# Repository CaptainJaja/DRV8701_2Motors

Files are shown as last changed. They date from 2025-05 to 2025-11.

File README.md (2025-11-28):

# Driver DRV8701 – Dual H-Bridge 40 V / 10 A (15 A peak)

> PCB designed with **KiCad** for driving **two brushed DC motors** up to 40 V / 10 A.
> Each channel uses a TI **DRV8701** driver paired with four **TPH1R403NL** power MOSFETs.
> The board integrates **encoder feedback** for PID control, as well as **current regulation** handled directly by the DRV8701.
> The current limit is set to **3 A**: above this value, the driver applies **PWM current chopping** to maintain the current below the set point.

---

## ⭐ Sponsor: PCBWay

This project was **sponsored by PCBWay**, who kindly provided the PCBs for prototyping.
The PCB quality is excellent and the support very responsive.

👉 **PCBWay Link:**


Thanks again to Liam and the PCBWay team for their support!

---

## Main Specifications

| Parameter | Value |
| --- | --- |
| Supply voltage VM | 7 – 40 V |
| Continuous current/motor | 10 A (4-layer PCB, 1 oz copper) |
| Peak current | 15 A (≤ 100 ms) |
| Chopped current limit | 3 A (via DRV8701) |
| Topology | 2 × full H-bridge (DRV8701 + 4 MOSFETs each) |
| Control signals | PH / EN / nSLEEP (TTL 3.3 V / 5 V) |
| LED indication | **EN** (active when nSLEEP = HIGH) |
| NeoPixel indication | Battery status (>25 V / 23–25 V / <23 V) |
| PCB dimensions | 100 mm × 40 mm |

---

## Thermal Management

* DRV8701 **exposed pad** connected to the GND plane through thermal vias.
* **TPH1R403NL (SOP-Advance)** MOSFETs soldered onto a large copper area + internal plane for heat spreading.
* Bulk decoupling capacitors: **470 µF / 50 V**, low ESR.

---

## PCB Views

### Component side

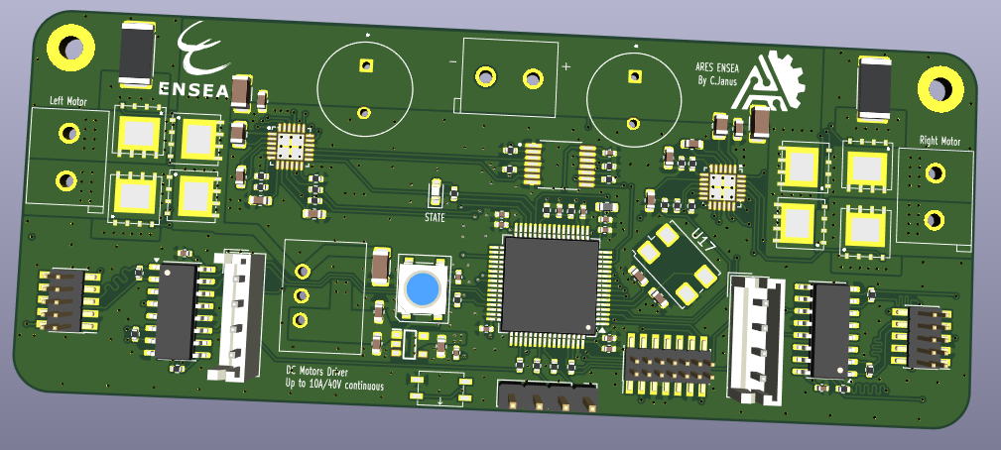
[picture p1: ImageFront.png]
PCB Front


### Bottom copper side

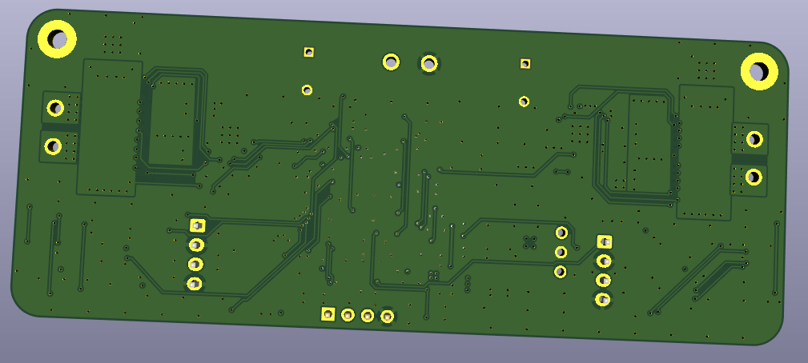
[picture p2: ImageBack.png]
PCB Back


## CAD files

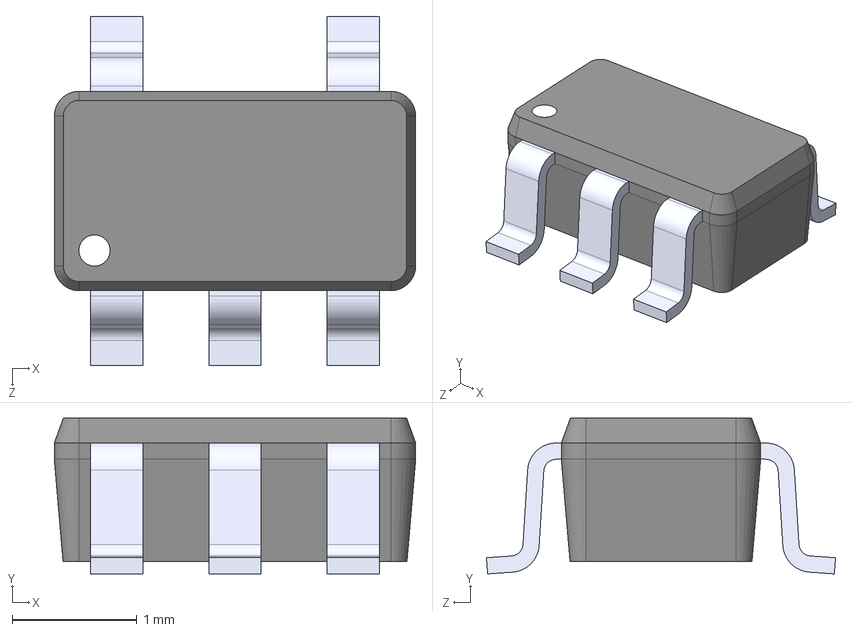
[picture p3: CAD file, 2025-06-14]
BU33SD5WG-TR/BU33SD5WG-TR.step
2.90 x 1.25 x 2.80 mm

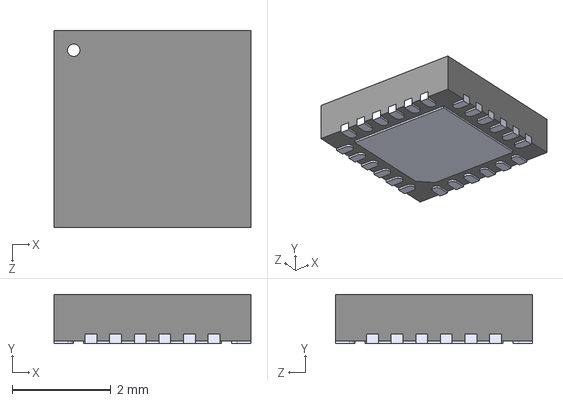
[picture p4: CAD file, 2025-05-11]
DRV8701ERGER/DRV8701ERGER.step
4.00 x 1.00 x 4.00 mm

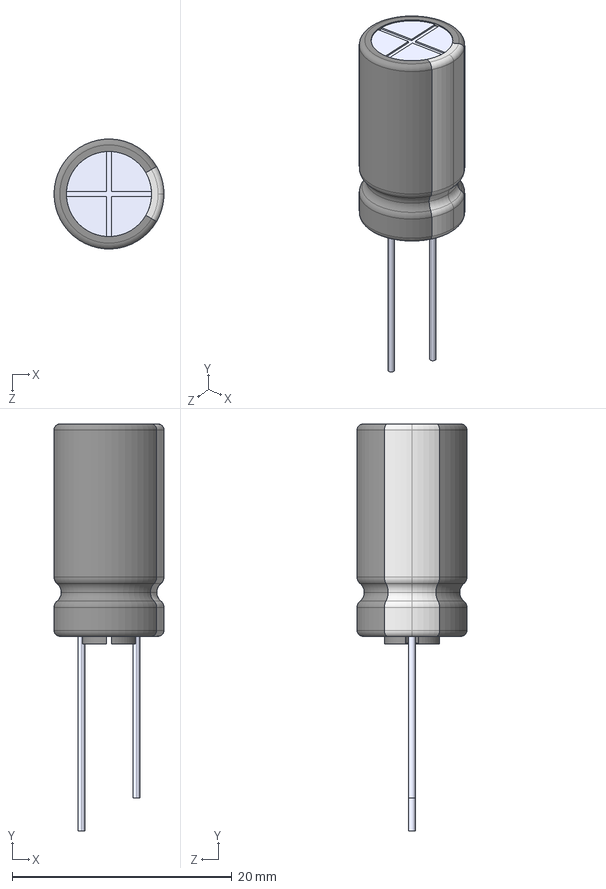
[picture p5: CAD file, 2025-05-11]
ECA1HHG471/ECA1HHG471.step
10.0 x 37.0 x 9.99 mm

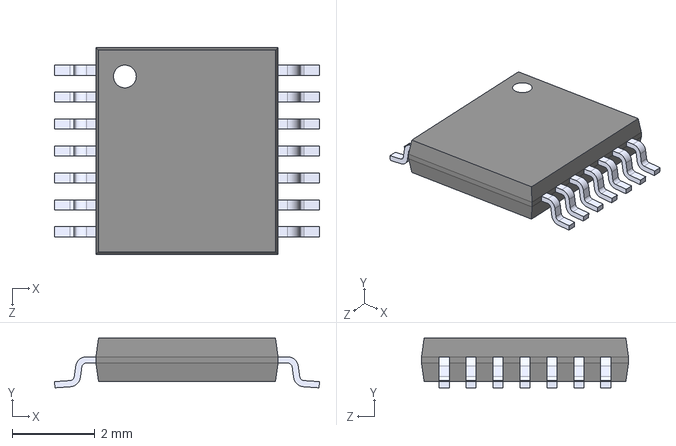
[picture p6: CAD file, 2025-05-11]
SN74HC125PWR/SN74HC125PWR.step
6.40 x 1.20 x 5.00 mm

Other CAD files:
switch_472121010111/472121010111.step

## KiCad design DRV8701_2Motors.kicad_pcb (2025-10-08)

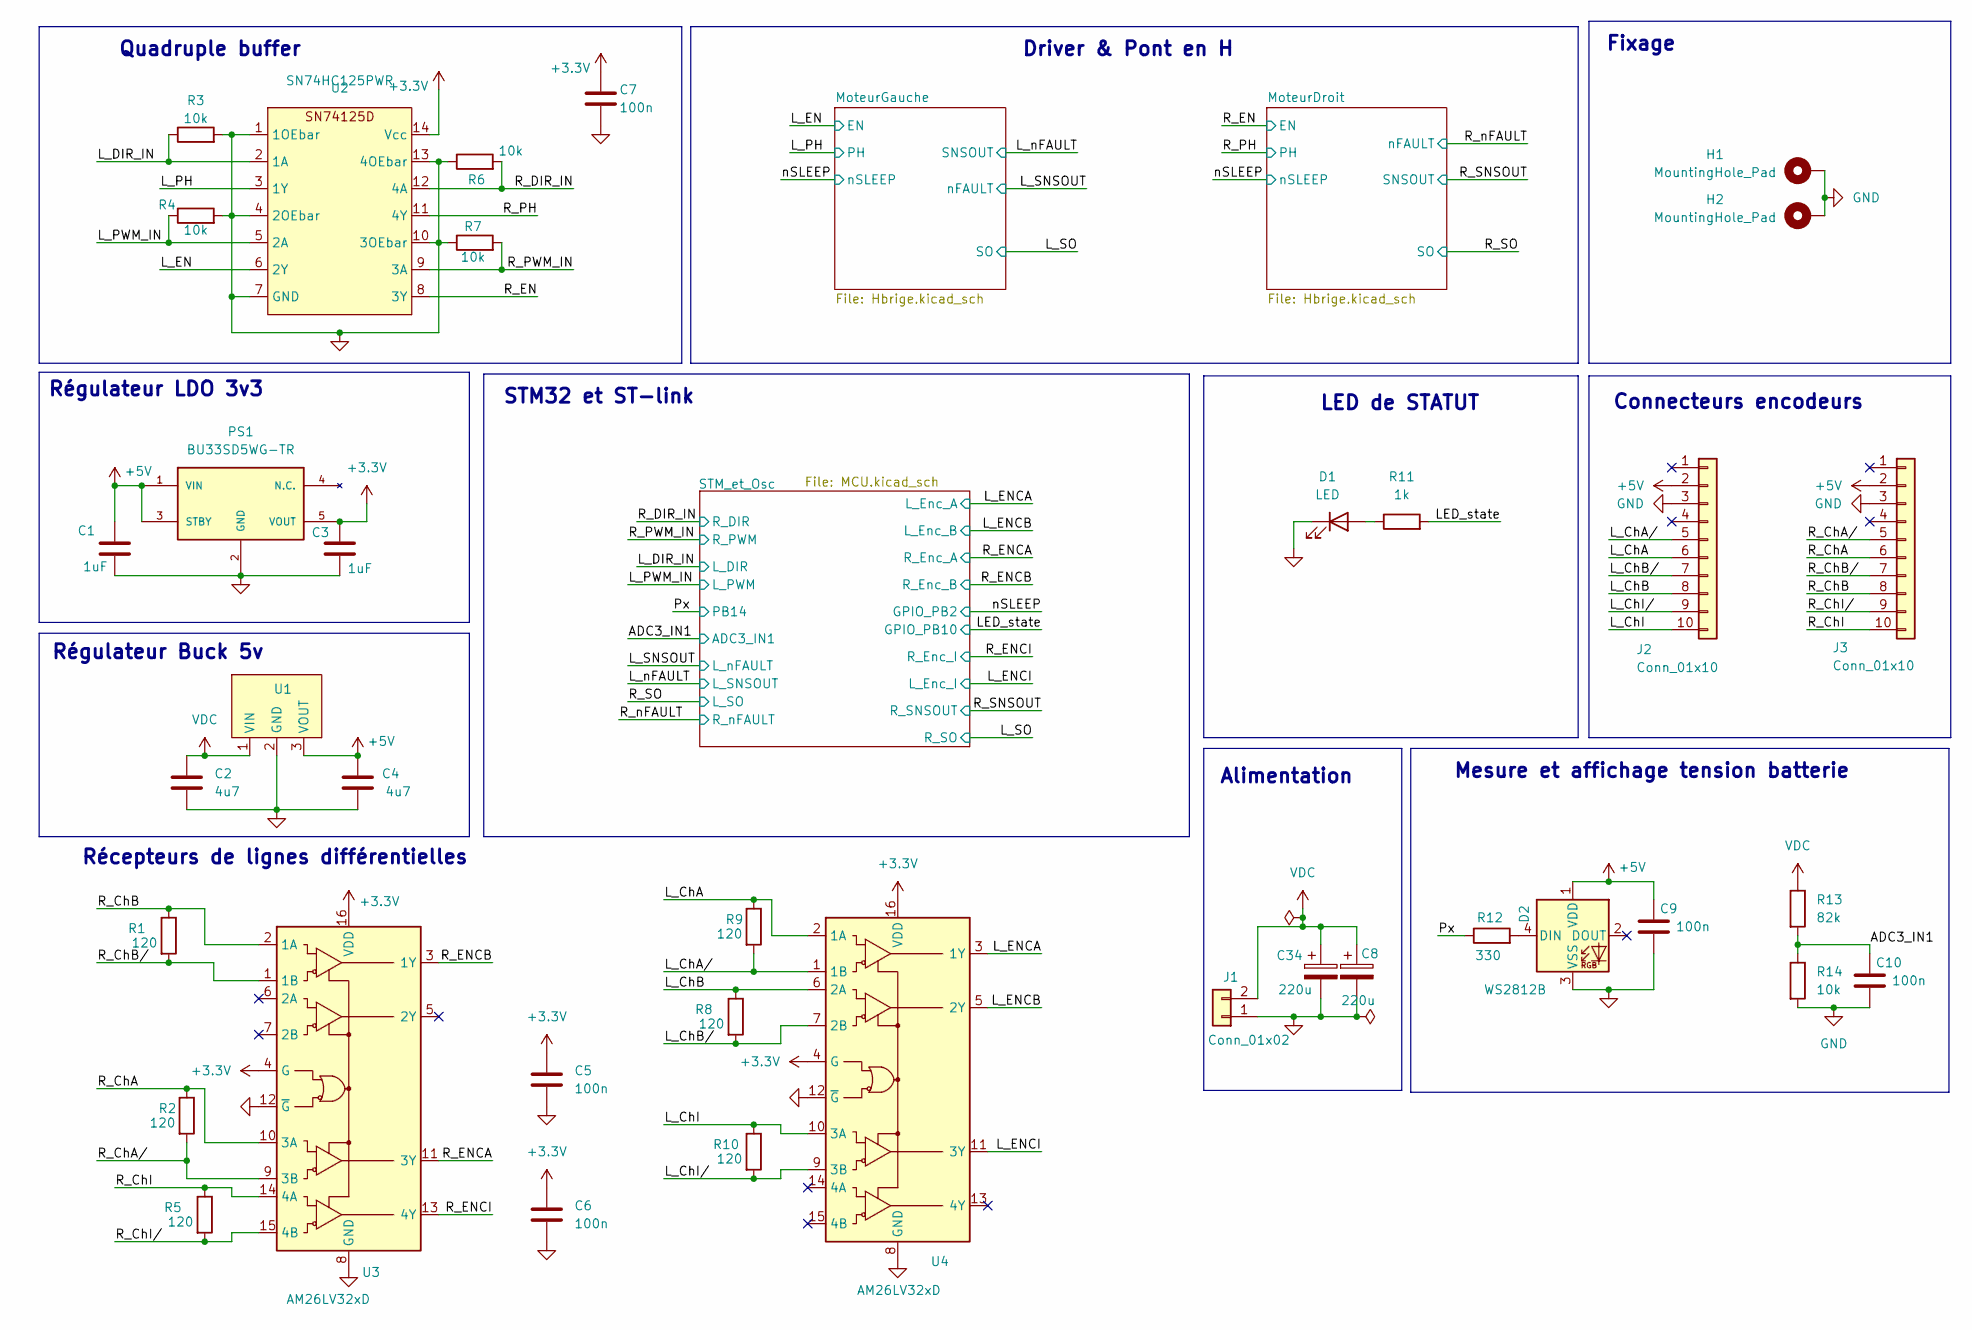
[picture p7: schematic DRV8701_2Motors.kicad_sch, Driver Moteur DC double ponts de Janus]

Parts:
C1, C3: 1uF; C_0603_1608Metric
C2: 4u7; C_1206_3216Metric
C4: 4u7; C_0603_1608Metric
C5, C6, C7, C9, C10: 100n; C_0402_1005Metric
C8, C34: 220u; ECA1HHG471
D1: LED; LED_0603_1608Metric_Pad1.05x0.95mm_HandSolder
D2: WS2812B; LED_WS2812B_PLCC4_5.0x5.0mm_P3.2mm
H1, H2: MountingHole_Pad; MountingHole_2.5mm_Pad
J1: Conn_01x02; KF301-5.0-2P
J2, J3: Conn_01x10; PinHeader_2x05_P1.27mm_Vertical_SMD
PS1: BU33SD5WG-TR; SOT95P280X125-5N; Mouser_Part_Number 755-BU33SD5WG-TR
R1, R2, R5, R8, R9, R10: 120; R_0402_1005Metric
R3, R4, R6, R7, R14: 10k; R_0402_1005Metric
R11: 1k; R_0402_1005Metric
R12: 330; R_0402_1005Metric
R13: 82k; R_0402_1005Metric
U1: StepDown3v3; MPN 173010x78
U2: SN74HC125PWR
U3, U4: AM26LV32xD; SOIC-16_3.9x9.9mm_P1.27mm

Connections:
+3.3V: C3.1, C5.1, C6.1, C7.1, PS1.5 (VOUT), U2.14 (Vcc), U3.4 (G), U3.16 (VDD), U4.4 (G), U4.16 (VDD); also elsewhere on the board
+5V: C1.1, C4.1, C9.2, D2.1 (VDD), J2.2, J3.2, PS1.1 (VIN), PS1.3 (STBY), U1.3 (VOUT)
/ADC3_IN1: C10.2, R13.2, R14.1; also elsewhere on the board
/LED_state: R11.2; also elsewhere on the board
/L_ChA: J2.6, R9.1, U4.2 (1A)
/L_ChA/: J2.5, R9.2, U4.1 (1B)
/L_ChB: J2.8, R8.1, U4.6 (2A)
/L_ChB/: J2.7, R8.2, U4.7 (2B)
/L_ChI: J2.10, R10.1, U4.10 (3A)
/L_ChI/: J2.9, R10.2, U4.9 (3B)
/L_DIR_IN: R3.1, U2.2 (1A); also elsewhere on the board
/L_EN: U2.6 (2Y); also elsewhere on the board
/L_ENCA: U4.3 (1Y); also elsewhere on the board
/L_ENCB: U4.5 (2Y); also elsewhere on the board
/L_ENCI: U4.11 (3Y); also elsewhere on the board
/L_PH: U2.3 (1Y); also elsewhere on the board
/L_PWM_IN: R4.1, U2.5 (2A); also elsewhere on the board
/Px: R12.1; also elsewhere on the board
/R_ChA: J3.6, R2.1, U3.10 (3A)
/R_ChA/: J3.5, R2.2, U3.9 (3B)
/R_ChB: J3.8, R1.1, U3.2 (1A)
/R_ChB/: J3.7, R1.2, U3.1 (1B)
/R_ChI: J3.10, R5.1, U3.14 (4A)
/R_ChI/: J3.9, R5.2, U3.15 (4B)
/R_DIR_IN: R6.2, U2.12 (4A); also elsewhere on the board
/R_EN: U2.8 (3Y); also elsewhere on the board
/R_ENCA: U3.11 (3Y); also elsewhere on the board
/R_ENCB: U3.3 (1Y); also elsewhere on the board
/R_ENCI: U3.13 (4Y); also elsewhere on the board
/R_PH: U2.11 (4Y); also elsewhere on the board
/R_PWM_IN: R7.2, U2.9 (3A); also elsewhere on the board
GND: C1.2, C2.2, C3.2, C4.2, C5.2, C6.2, C7.2, C8.2, C9.1, C10.1, C34.2, D1.1 (K), D2.3 (VSS), H1.1, H2.1, J1.1, J2.3, J3.3, PS1.2 (GND), R3.2, R4.2, R6.1, R7.1, R14.2, U1.2 (GND), U2.1 (1OEbar), U2.4 (2OEbar), U2.7 (GND), U2.10 (3OEbar), U2.13 (4OEbar), U3.8 (GND), U3.12 (~G), U4.8 (GND), U4.12 (~G); also elsewhere on the board
unnamed: D1.2 (A), R11.1
unnamed: D2.4 (DIN), R12.2
VDC: C2.1, C8.1, C34.1, J1.2, R13.1, U1.1 (VIN); also elsewhere on the board

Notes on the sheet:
STM32 et ST-link
Driver & Pont en H
Fixage
Quadruple buffer
Régulateur LDO 3v3
Connecteurs encodeurs
Alimentation
LED de STATUT
Récepteurs de lignes différentielles
Régulateur Buck 5v
Mesure et affichage tension batterie

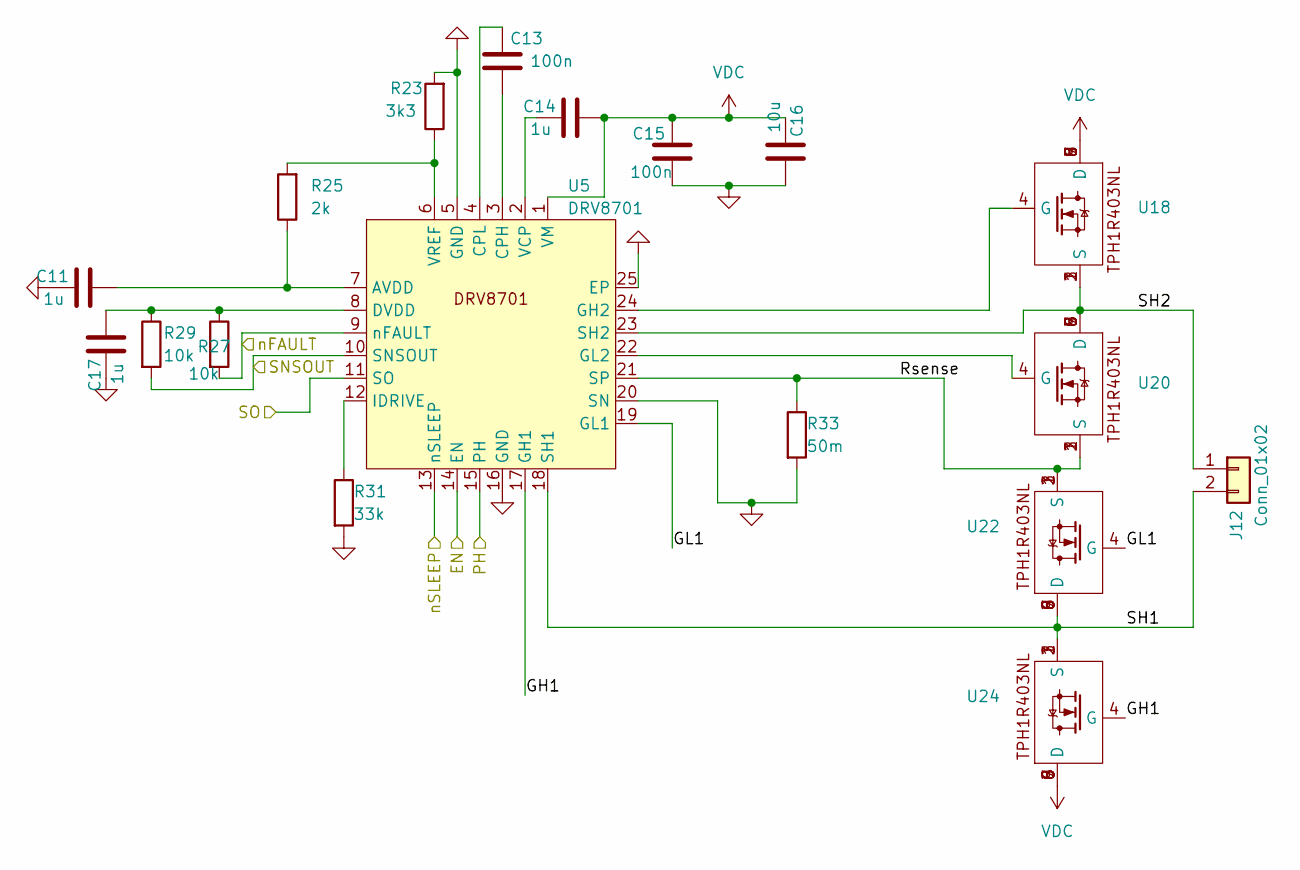
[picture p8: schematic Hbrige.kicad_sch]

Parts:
C11, C17: 1u; C_0603_1608Metric
C13, C15: 100n; C_0603_1608Metric
C14: 1u; C_0805_2012Metric
C16: 10u; C_1206_3216Metric
J12: Conn_01x02; KF301-5.0-2P
R23: 3k3; R_0402_1005Metric
R25: 2k; R_0402_1005Metric
R27, R29: 10k; R_0402_1005Metric
R31: 33k; R_0402_1005Metric
R33: 50m; R_2512_6332Metric
U5: DRV8701; DRV8701ERGER
U18, U20, U22, U24: TPH1R403NL; MPN TPH1R403NL

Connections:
/MoteurDroit/GH1: U5.17 (GH1), U24.4 (G)
/MoteurDroit/GL1: U5.19 (GL1), U22.4 (G)
/MoteurDroit/Rsense: R33.1, U5.21 (SP), U20.1 (S), U20.2 (S), U20.3 (S), U22.1 (S), U22.2 (S), U22.3 (S)
/MoteurDroit/SH1: J12.2, U5.18 (SH1), U22.5 (D), U22.6 (D), U22.7 (D), U22.8 (D), U22.9 (D), U24.1 (S), U24.2 (S), U24.3 (S)
/MoteurDroit/SH2: J12.1, U5.23 (SH2), U18.1 (S), U18.2 (S), U18.3 (S), U20.5 (D), U20.6 (D), U20.7 (D), U20.8 (D), U20.9 (D)
/R_EN: U5.14 (EN); also elsewhere on the board
/R_PH: U5.15 (PH); also elsewhere on the board
/R_SNSOUT: R29.2, U5.10 (SNSOUT); also elsewhere on the board
/R_SO: U5.11 (SO); also elsewhere on the board
/R_nFAULT: R27.2, U5.9 (nFAULT); also elsewhere on the board
/nSLEEP: U5.13 (nSLEEP); also elsewhere on the board
GND: C11.2, C15.1, C16.1, C17.2, R23.2, R31.2, R33.2, U5.5 (GND), U5.16 (GND), U5.20 (SN), U5.25 (EP); also elsewhere on the board
unnamed: C11.1, R25.1, U5.7 (AVDD)
unnamed: C13.1, U5.3 (CPH)
unnamed: C13.2, U5.4 (CPL)
unnamed: C17.1, R27.1, R29.1, U5.8 (DVDD)
unnamed: R31.1, U5.12 (IDRIVE)
unnamed: C14.2, U5.2 (VCP)
unnamed: R23.1, R25.2, U5.6 (VREF)
unnamed: U5.24 (GH2), U18.4 (G)
unnamed: U5.22 (GL2), U20.4 (G)
VDC: C14.1, C15.2, C16.2, U5.1 (VM), U18.5 (D), U18.6 (D), U18.7 (D), U18.8 (D), U18.9 (D), U24.5 (D), U24.6 (D), U24.7 (D), U24.8 (D), U24.9 (D); also elsewhere on the board

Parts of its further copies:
C12, C18: 1u; C_0603_1608Metric
C19, C21: 100n; C_0603_1608Metric
C20: 1u; C_0805_2012Metric
C22: 10u; C_1206_3216Metric
J13: Conn_01x02; KF301-5.0-2P
R24: 3k3; R_0402_1005Metric
R26: 2k; R_0402_1005Metric
R28, R30: 10k; R_0402_1005Metric
R32: 33k; R_0402_1005Metric
R34: 50m; R_2512_6332Metric
U10: DRV8701; DRV8701ERGER
U19, U21, U23, U25: TPH1R403NL; MPN TPH1R403NL

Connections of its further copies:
/L_EN: U10.14 (EN); also elsewhere on the board
/L_PH: U10.15 (PH); also elsewhere on the board
/L_SNSOUT: R28.2, U10.9 (nFAULT); also elsewhere on the board
/L_SO: U10.11 (SO); also elsewhere on the board
/L_nFAULT: R30.2, U10.10 (SNSOUT); also elsewhere on the board
/MoteurGauche/GH1: U10.17 (GH1), U25.4 (G)
/MoteurGauche/GL1: U10.19 (GL1), U23.4 (G)
/MoteurGauche/Rsense: R34.1, U10.21 (SP), U21.1 (S), U21.2 (S), U21.3 (S), U23.1 (S), U23.2 (S), U23.3 (S)
/MoteurGauche/SH1: J13.2, U10.18 (SH1), U23.5 (D), U23.6 (D), U23.7 (D), U23.8 (D), U23.9 (D), U25.1 (S), U25.2 (S), U25.3 (S)
/MoteurGauche/SH2: J13.1, U10.23 (SH2), U19.1 (S), U19.2 (S), U19.3 (S), U21.5 (D), U21.6 (D), U21.7 (D), U21.8 (D), U21.9 (D)
/nSLEEP: U10.13 (nSLEEP); also elsewhere on the board
GND: C12.2, C18.2, C21.1, C22.1, R24.2, R32.2, R34.2, U10.5 (GND), U10.16 (GND), U10.20 (SN), U10.25 (EP); also elsewhere on the board
unnamed: C12.1, R26.1, U10.7 (AVDD)
unnamed: C19.1, U10.3 (CPH)
unnamed: C19.2, U10.4 (CPL)
unnamed: C18.1, R28.1, R30.1, U10.8 (DVDD)
unnamed: U10.24 (GH2), U19.4 (G)
unnamed: U10.22 (GL2), U21.4 (G)
unnamed: R32.1, U10.12 (IDRIVE)
unnamed: C20.2, U10.2 (VCP)
unnamed: R24.1, R26.2, U10.6 (VREF)
VDC: C20.1, C21.2, C22.2, U10.1 (VM), U19.5 (D), U19.6 (D), U19.7 (D), U19.8 (D), U19.9 (D), U25.5 (D), U25.6 (D), U25.7 (D), U25.8 (D), U25.9 (D); also elsewhere on the board

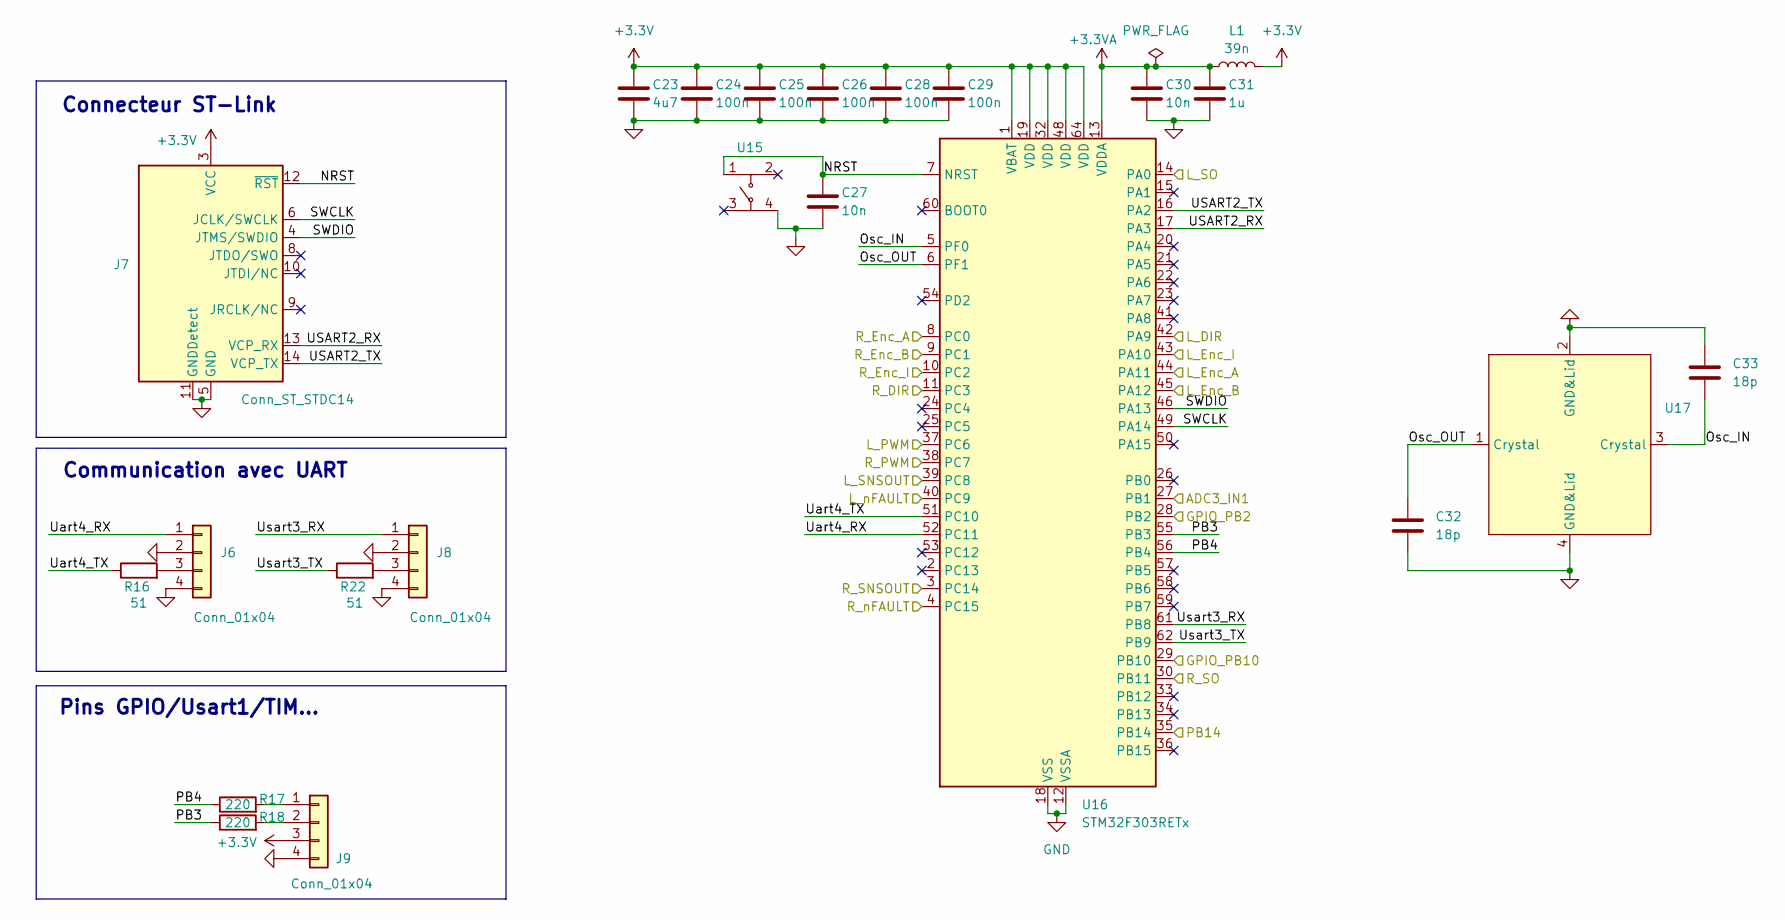
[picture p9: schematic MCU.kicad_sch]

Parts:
C23: 4u7; C_0402_1005Metric
C24, C25, C26, C28, C29: 100n; C_0402_1005Metric
C27, C30: 10n; C_0402_1005Metric
C31: 1u; C_0402_1005Metric
C32, C33: 18p; C_0603_1608Metric
J6, J8: Conn_01x04; JST_EH_B4B-EH-A_1x04_P2.50mm_Vertical
J7: Conn_ST_STDC14; PinHeader_2x07_P1.27mm_Vertical_SMD
J9: Conn_01x04; PinHeader_1x04_P2.54mm_Vertical
L1: 39n; L_0603_1608Metric
R16, R22: 51; R_0402_1005Metric
R17, R18: 220; R_0402_1005Metric
U15: WS-TASU SMT Tact Switch 4.7x3.5 mm side push
U16: STM32F303RETx; LQFP-64_10x10mm_P0.5mm
U17: Crystal_SMD_7050-4Pin_7.0x5.0mm

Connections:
+3.3V: C23.1, C24.1, C25.1, C26.1, C28.1, C29.1, J7.3 (VCC), J9.3, L1.2, U16.1 (VBAT), U16.19 (VDD), U16.32 (VDD), U16.48 (VDD), U16.64 (VDD); also elsewhere on the board
+3.3VA: C30.1, C31.1, L1.1, U16.13 (VDDA)
/ADC3_IN1: U16.27 (PB1); also elsewhere on the board
/LED_state: U16.29 (PB10); also elsewhere on the board
/L_DIR_IN: U16.42 (PA9); also elsewhere on the board
/L_ENCA: U16.44 (PA11); also elsewhere on the board
/L_ENCB: U16.45 (PA12); also elsewhere on the board
/L_ENCI: U16.43 (PA10); also elsewhere on the board
/L_PWM_IN: U16.37 (PC6); also elsewhere on the board
/L_SNSOUT: U16.40 (PC9); also elsewhere on the board
/L_SO: U16.30 (PB11); also elsewhere on the board
/L_nFAULT: U16.39 (PC8); also elsewhere on the board
/Px: U16.35 (PB14); also elsewhere on the board
/R_DIR_IN: U16.11 (PC3); also elsewhere on the board
/R_ENCA: U16.8 (PC0); also elsewhere on the board
/R_ENCB: U16.9 (PC1); also elsewhere on the board
/R_ENCI: U16.10 (PC2); also elsewhere on the board
/R_PWM_IN: U16.38 (PC7); also elsewhere on the board
/R_SNSOUT: U16.3 (PC14); also elsewhere on the board
/R_SO: U16.14 (PA0); also elsewhere on the board
/R_nFAULT: U16.4 (PC15); also elsewhere on the board
/STM_et_Osc/NRST: C27.1, J7.12 (~RST), U15.1, U16.7 (NRST)
/STM_et_Osc/Osc_IN: C33.2, U16.5 (PF0), U17.3 (Crystal)
/STM_et_Osc/Osc_OUT: C32.1, U16.6 (PF1), U17.1 (Crystal)
/STM_et_Osc/PB3: R18.1, U16.55 (PB3)
/STM_et_Osc/PB4: R17.1, U16.56 (PB4)
/STM_et_Osc/SWCLK: J7.6 (JCLK/SWCLK), U16.49 (PA14)
/STM_et_Osc/SWDIO: J7.4 (JTMS/SWDIO), U16.46 (PA13)
/STM_et_Osc/USART2_RX: J7.13 (VCP_RX), U16.17 (PA3)
/STM_et_Osc/USART2_TX: J7.14 (VCP_TX), U16.16 (PA2)
/STM_et_Osc/Uart4_RX: J6.1, U16.52 (PC11)
/STM_et_Osc/Uart4_TX: R16.1, U16.51 (PC10)
/STM_et_Osc/Usart3_RX: J8.1, U16.61 (PB8)
/STM_et_Osc/Usart3_TX: R22.1, U16.62 (PB9)
/nSLEEP: U16.28 (PB2); also elsewhere on the board
GND: C23.2, C24.2, C25.2, C26.2, C27.2, C28.2, C29.2, C30.2, C31.2, C32.2, C33.1, J6.2, J6.4, J7.5 (GND), J7.7 (GND), J7.11 (GNDDetect), J8.2, J8.4, J9.4, U15.4, U16.12 (VSSA), U16.18 (VSS), U16.31 (VSS), U16.47 (VSS), U16.63 (VSS), U17.2 (GND&Lid), U17.4 (GND&Lid); also elsewhere on the board
unnamed: J6.3, R16.2
unnamed: J8.3, R22.2
unnamed: J9.1, R17.2
unnamed: J9.2, R18.2

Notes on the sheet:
Pins GPIO/Usart1/TIM...
Communication avec UART
Connecteur ST-Link

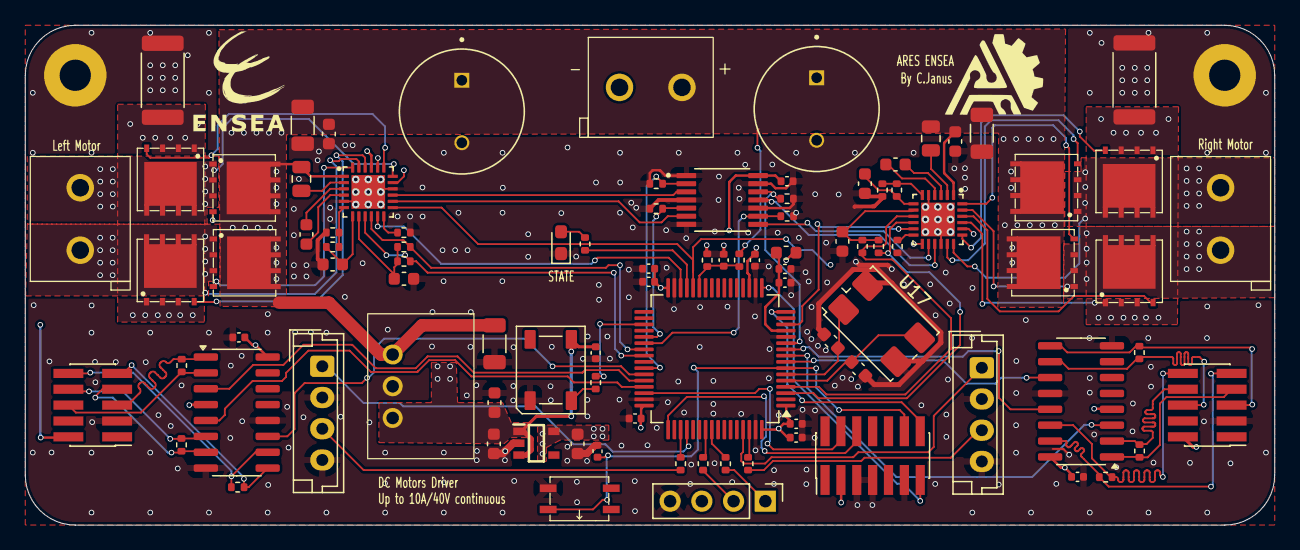
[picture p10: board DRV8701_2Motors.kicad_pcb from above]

Board: 4 copper layers, 100.0 x 40.0 mm, 96 parts (0 on the bottom side), 88 nets.

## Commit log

2025-05-11 Premier import du driver DRV8701 (2 moteurs)
    [DRV8701_2Motors.kicad_pcb, DRV8701_2Motors.kicad_sch]
2025-05-11 modif README
    [472121010111.step, DRV8701ERGER.step, DRV8701_2Motors.kicad_pcb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]
2025-05-11 modif épaisseur cuivre
    [DRV8701_2Motors.kicad_pcb]
2025-05-11 petite correction sur les remplissages de zone
    [DRV8701_2Motors.kicad_pcb]
2025-06-14 PCB V2 : adapté pour les moteurs maxons, avec l'asservissement directement dessus. Finalisation du schématique
    [BU33SD5WG-TR.step, DRV8701_2Motors.kicad_pcb, DRV8701_2Motors.kicad_sch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]
2025-06-16 finalisation schematique
    [DRV8701_2Motors.kicad_sch, MCU.kicad_sch]
2025-06-16 reintroduction des mosfet (au lieu des demi-ponts en H), début routage
    [DRV8701_2Motors.kicad_pcb, DRV8701_2Motors.kicad_sch, Hbrige.kicad_sch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]
2025-06-17 maj PCB
    [DRV8701_2Motors.kicad_pcb, DRV8701_2Motors.kicad_sch, Hbrige.kicad_sch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]
2025-06-17 finalisation PCB
    [DRV8701_2Motors.kicad_pcb, DRV8701_2Motors.kicad_sch, Hbrige.kicad_sch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]
2025-06-18 MAJ vias thermiques des drivers
    [DRV8701_2Motors-B_Cu.gbl, DRV8701_2Motors-B_Mask.gbs, DRV8701_2Motors-B_Paste.gbp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]
2025-06-18 final push
    [DRV8701_2Motors-B_Cu.gbl, DRV8701_2Motors-B_Mask.gbs, DRV8701_2Motors-B_Paste.gbp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]
2025-06-21 finalisation V2 -- manque plus que les vias gnd
    [DRV8701_2Motors.kicad_pcb, DRV8701_2Motors.kicad_sch, Hbrige.kicad_sch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]
2025-06-21 finalisation PCB v2
    [DRV8701_2Motors.kicad_pcb, MCU.kicad_sch]
2025-06-28 alignement des drv
    [DRV8701_2Motors-B_Cu.gbl, DRV8701_2Motors-B_Mask.gbs, DRV8701_2Motors-B_Paste.gbp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]
2025-06-28 maj README img
    [DRV8701_2Motors-B_Cu.gbl, DRV8701_2Motors-B_Mask.gbs, DRV8701_2Motors-B_Paste.gbp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]
2025-07-01 gerber avec reduction 15% du paste
    [DRV8701_2Motors-B_Cu.gbl, DRV8701_2Motors-B_Mask.gbs, DRV8701_2Motors-B_Paste.gbp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]
2025-09-05 modif footprints des condo de puissance
    [DRV8701_2Motors.kicad_pcb, DRV8701_2Motors.kicad_sch, Hbrige.kicad_sch]
2025-09-16 V2 Driver-- avec control de courant
    [DRV8701_2Motors.kicad_pcb, DRV8701_2Motors.kicad_sch, Hbrige.kicad_sch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]
2025-09-19 maj README
    [DRV8701_2Motors-B_Cu.gbl, DRV8701_2Motors-B_Mask.gbs, DRV8701_2Motors-B_Paste.gbp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]
2025-09-19 maj readme, supprimé deux vias non utiles
    [DRV8701_2Motors.kicad_pcb]
2025-09-19 final push--tous les composants sur le Front
    [DRV8701_2Motors.kicad_pcb]
2025-09-20 alignement connecteur, changement connecteur
    [DRV8701_2Motors-B_Cu.gbl, DRV8701_2Motors-B_Mask.gbs, DRV8701_2Motors-B_Paste.gbp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]
2025-09-20 maj readme driver
2025-10-08 last push
    [DRV8701_2Motors-B_Cu.gbl, DRV8701_2Motors-B_Mask.gbs, DRV8701_2Motors-B_Paste.gbp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]
